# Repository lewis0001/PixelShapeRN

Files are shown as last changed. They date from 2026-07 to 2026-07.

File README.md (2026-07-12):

# BOTFORGE

> Codename `botforge` — rename with one global find/replace when the brand is chosen.

An open, modular robotics platform — "LEGO for real robots." A single manifest
file per robot (`robots/<id>/robot.yaml`) is compiled by the engine into every
artifact: CAD files, wiring diagrams, assembly instructions, BOM, docs,
firmware config, simulator model, and store page.

**`PLAN.md` is the source of truth.** Deviations are logged in
`docs/DECISIONS.md`; phase completion reports live in `docs/reports/`.

## Repository layout

| Path | What |
| --- | --- |
| `apps/web` | Next.js 14 site (catalog, builder, sim, drive, flash, store) |
| `apps/docs` | Astro Starlight docs (per-robot guides, engine-generated) |
| `packages/engine` | Python compiler: manifest → all artifacts. CLI `botforge` |
| `packages/firmware` | Universal ESP32-S3 firmware (PlatformIO) |
| `packages/behavior-ts` | Behavior Script JSON types + reference interpreter |
| `packages/sim` | three.js + Rapier browser simulator |
| `packages/shared` | Shared TS types |
| `registry/` | Electronic module + fastener catalog (YAML) |
| `robots/` | Per-robot data definitions (the only place robots live) |
| `infra/` | Engine Docker image, slicer profiles |

## Prerequisites

- Node 20+ and pnpm 10 (`corepack enable` or `npm i -g pnpm`)
- Python 3.11+ and [uv](https://docs.astral.sh/uv/)
- Optional: PlatformIO (`pip install platformio`) for firmware
- Optional: Docker (for the full engine environment with CadQuery/PrusaSlicer)

## Commands

| Command | Does |
| --- | --- |
| `pnpm install` | Install all JS workspace deps  |
| `pnpm dev` | Web + docs dev servers (turbo) |
| `pnpm build` | Build all JS apps/packages |
| `pnpm test` | All JS tests |
| `uv sync --project packages/engine` | Install engine deps |
| `uv run --project packages/engine botforge validate robots/rover-v1` | Schema + registry validation |
| `uv run --project packages/engine botforge build robots/rover-v1` | Full artifact build → `dist/`  |
| `pnpm fw:build` | Firmware build (`pio run`) |
| `pnpm fw:test` | Behavior VM native tests |
| `pnpm e2e` | Playwright suite (Phase 4) |

## Licensing

Mixed-license monorepo — see `docs/DECISIONS.md` and PLAN.md §D:

- Platform code (`apps/*`, `packages/engine`, `packages/shared`): proprietary — `LICENSE-CODE.md`
- `packages/firmware`, `packages/behavior-ts`, `packages/sim`: GPL-3.0
- `robots/`, `registry/`, generated docs/CAD: CC BY-NC-SA 4.0

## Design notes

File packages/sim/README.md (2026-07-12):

# @botforge/sim

Browser + headless robot simulator (PLAN.md Phase 3): Rapier physics at a
fixed 120 Hz (`SIM_FIXED_STEP_HZ`), three.js visuals, virtual sensors, and a
§5.4-protocol `SimLink` so `/play` and `/drive` talk to the simulated robot
through the same `RobotLink` interface as real hardware. Licensed under
GPL-3.0.

- **`SimWorld`** — loads an engine-generated URDF (+ STL meshes) into a
  seeded, deterministic physics world. Differential drive (v_max 0.45 m/s,
  wheel radius/track derived from the URDF continuous joints), servo joints
  as position motors, per-link bbox colliders. `collidersOnly: true` skips
  the three.js scene for Node/CI use.
- **`VirtualSensors`** — ToF raycast fan (2000 mm max, σ = 2 mm seeded
  noise), line sensors sampling the arena ground field (0–4095, dark =
  high), linear battery discharge (4.1 → 3.5 V over 20 min of driving).
- **`ARENAS`** — `open_floor`, `line_oval` (procedural stadium track with a
  lap-progress parametrization), `obstacle_pen` (walled 1.5 × 1.5 m box with
  seeded random blocks).
- **`SimLink`** — implements the §5.4 message set (`hello`/`hello.ack`,
  `mode`, `cmd.*`, 5 Hz `telemetry`, `log`) and runs BSJ behaviors through
  `@botforge/behavior-ts` at 50 Hz sim time. `loadBehavior()` + `ctl()`
  mirror `POST /api/behavior[/ctl]`.
- **`loadRobotUrdf`** — browser-only urdf-loader helper for articulated
  visual meshes.

The headless gate tests in `test/gates.test.ts` double as regression gates
for the engine's URDF output. Fixtures in `test/fixtures/rover-v1/` are a
copy of `dist/rover-v1/urdf/` (regenerate with
`uv run --project packages/engine botforge build robots/rover-v1 --only cad,urdf`).

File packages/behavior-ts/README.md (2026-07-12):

# @botforge/behavior-ts

Behavior Script JSON (BSJ) v1 — types, zod schema, and the **reference
interpreter** for botforge robot behaviors (plan §5.3). Licensed under
GPL-3.0.

- `src/types.ts` — BSJ types + `BSJ_VERSION` + `BSJ_LIMITS`
- `src/schema.ts` — zod schema, limits enforcement, `parseBsj()`
- `src/interpreter.ts` — `BsjInterpreter` with an injectable `RobotAdapter`
  (`load` / `start` / `tick` / `stop` / `onButton`, 50 Hz stored-deadline
  stack machine)
- `SEMANTICS.md` — the normative execution semantics, shared with the C++
  firmware VM (`packages/firmware/src/vm/`)
- `fixtures/` — golden-trace fixtures run by **both** interpreters
  (`pnpm --filter @botforge/behavior-ts test` and
  `pio test -d packages/firmware -e native`); see `fixtures/README.md`

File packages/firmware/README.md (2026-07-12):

# botforge firmware

Phase-0 PlatformIO project for the universal ESP32-S3 robot firmware.
Right now it is just a scaffold: a blink on the ESP32-S3-DevKitC-1 and a
trivial native Unity test.

## Prerequisites

- [PlatformIO Core](https://docs.platformio.org/en/latest/core/installation/index.html) (`pio`)

## Build (ESP32-S3)

```sh
pio run
```

This builds the `esp32s3` environment. Note: the project uses the
[pioarduino fork](https://github.com/pioarduino/platform-espressif32) of the
espressif32 platform because the official PlatformIO platform does not support
arduino-esp32 core 3.x (see the comment in `platformio.ini`).

## Test (native, host machine)

```sh
pio test -e native
```

Runs the Unity tests under `test/native/` on your host — no hardware needed.

## Flash

```sh
pio run -t upload
```

With `ARDUINO_USB_CDC_ON_BOOT=1` the board enumerates on its native USB port;
monitor with:

```sh
pio device monitor
```

(115200 baud, configured in `platformio.ini`.)

## Layout

- `src/main.cpp` — Phase-0 blink placeholder (compiled out for `native`)
- `lib/vmcore/` — seed of the firmware VM core (currently just `clamp100`)
- `test/native/` — host-side Unity tests
- `partitions.csv` — 8MB flash: dual ~3MB OTA app slots + 1.5MB LittleFS

## Configuration (later phases)

Pin maps and robot configuration are **not** hardcoded here. In later phases
the botforge engine generates a `config.json` that is placed on the LittleFS
data partition and read at boot; the firmware stays universal across robots.

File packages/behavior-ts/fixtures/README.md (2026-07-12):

# BSJ golden-trace fixtures

Shared conformance fixtures for the **two** BSJ interpreters:

- TypeScript reference: `packages/behavior-ts/src/interpreter.ts`
  (run by `packages/behavior-ts/test/fixtures.test.ts`)
- C++ firmware VM: `packages/firmware/src/vm/`
  (run by `packages/firmware/test/native/test_vm/test_main.cpp`,
  `pio test -d packages/firmware -e native`)

Both harnesses execute every fixture listed in `index.json` and require the
**exact** ordered HAL-call trace. The semantics being tested are pinned in
`../SEMANTICS.md`.

## Fixture file format

```jsonc
{
  "name": "01_blink_sequence",
  "desc": "what this fixture proves",
  "tick_ms": 20, // scheduler period (50 Hz = 20)
  "run_ms": 600, // last tick timestamp (inclusive)
  "sensors": {
    "range.mm": [
      [0, 500],
      [300, 100],
    ],
  }, // step profiles
  "random": [0, 1], // scripted HAL random() results, in call order
  "buttons": [100, 340], // onButton() times (multiples of tick_ms, > 0)
  "program": {/* the BSJ program */},
  "expected": ["0 led 0 80 0 -1", "..."], // exact ordered trace
  "expect_error": "op budget exceeded", // optional: required error() after run
}
```

## Harness procedure (identical in TS and C++)

1. `load(program)` — must succeed.
2. `start(0)`.
3. For `t = tick_ms, 2·tick_ms, … , run_ms` (inclusive):
   set the mock clock to `t`; call `onButton(t)` once per entry in `buttons`
   equal to `t` (button presses are delivered **before** the tick); then
   `tick(t)`.
4. Compare the recorded trace to `expected`, element for element.
5. If `expect_error` is set: `running()` must be false and `error()` must
   equal it. Otherwise `error()` must be empty/null.

## Mock HAL

- Records one line per actuator/log call, prefixed with the current mock
  time: `drive <l> <r>` · `servo <id> <deg>` · `led <r> <g> <b> <id>` ·
  `led_off <id>` · `tone <hz> <ms>` · `log <level> <msg>`. An omitted
  `led`/`led_off` id records as `-1`. `readSensor`/`random`/`now` calls are
  **not** traced.
- `readSensor(name)`: the `sensors` map gives `[t, value]` step profiles
  (sorted by `t`); the value is the last entry with `t <= now`, or `0` when
  there is none (or the sensor is unlisted).
- `random(lo, hi)`: returns the next value from `random`, cycling back to the
  start when exhausted; returns `lo` if the list is empty/absent.

## Fixtures

| file | proves |
| --- | --- |
| 01_blink_sequence.json | sequential ops + `wait` deadlines resume at the first tick ≥ deadline; `on_tick` first fire |
| 02_drive_time_overlap.json | `drive_time` drive→wait→stop; a second handler interleaves while the first is blocked |
| 03_if_else_sensor.json | `if`/`else` branching on a scripted sensor profile |
| 04_while_break.json | `while` loop, `break` unwinding through nested `if`s, `change_var` |
| 05_repeat_nested.json | `repeat` (incl. nested repeat) iteration counts |
| 06_vars_math.json | `set_var`/`change_var`, `math` (+ − × ÷ min max), `cmp`, `logic`, `not`, `rand`, `call`s |
| 07_tick_skip.json | `on_tick` firings are skipped while the previous activation still runs; anchored schedule |
| 08_runaway_guard.json | >200 ops in one tick → runtime error: `drive 0 0` + `log 3` + halt |
| 09_on_button.json | `on_button` fires immediately; a press while the handler runs is skipped |
| 10_avoid_obstacles.json | the real shipped `avoid_obstacles` behavior against a scripted range profile + random seq |
| 11_servo_sweep.json | `servo_sweep` non-blocking interpolation: per-tick updates, exact endpoint emission |
| 12_div_zero.json | division by zero → runtime error trace and `error()` message |

## Regenerating `expected`

`BSJ_FIXTURES_UPDATE=1 pnpm --filter @botforge/behavior-ts test` rewrites each
fixture's `expected` (and nothing else) from the TypeScript reference
interpreter. Only do this after a deliberate, documented semantics change —
the C++ VM must then be re-verified against the new goldens.

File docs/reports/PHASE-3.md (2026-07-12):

# Phase 3 report — No-code builder + simulator

Date: 2026-07-12
Status: **complete** up to the two 🧍 items (phone spot-check; sim→real-robot send needs
the Phase-2 bench hardware).

## What was built

- **`/builder`** — 31 custom Blockly blocks covering the frozen §5.3 BSJ set exactly
  (Events / Move / Sense / Light & Sound / Logic / Loops / Variables). Pure codec
  `workspace ⇄ BSJ` with **lossless round-trip proven on all 3 rover behaviors and all
  12 shared interpreter fixtures** (plus a real-Blockly load/re-save pass). Zod
  validation, live 128-block/16 KB meter, examples menu, localStorage save/load,
  file up/download.
- **`packages/sim`** — `SimWorld` (Rapier, fixed 1/120 s step, fully seeded and
  deterministic: float-identical pose traces across runs), URDF-driven robot with
  diff-drive derived from the generated wheel joints, virtual ToF (5-ray fan, σ=2 mm),
  line sensors off a parametrized ground field, battery model; arenas `open_floor`,
  `line_oval`, `obstacle_pen`. `SimLink` implements the same §5.4 protocol as the
  firmware, running the shared `BsjInterpreter` at 50 Hz.
- **`/play`** — split view: sim canvas (orbit camera, arena picker, 1×/4× speed, BOOT
  button, LED overlay) beside the reused block editor. ▶ Run in Sim / ⏹ / ⟲ /
  ⬆ Send to Robot (POST `/api/behavior` + ctl run, then live robot logs/telemetry over
  WsLink). One program, two targets — P3 realized end to end.

## Acceptance checklist

- [x] Round-trip Blockly↔BSJ lossless on all fixtures (15/15 programs)
- [x] TS + C++ interpreters produce identical golden traces (Phase 2, 12 fixtures)
- [x] Headless sim gates green: `avoid_obstacles` in `obstacle_pen` 15 s →
      **1.614 m** displacement (> 1 m), max wall-contact streak 375 ms (< 2 s);
      `line_follow` on `line_oval` → **197.9 %** lap progress (≥ 60 %)
- [ ] 🧍 `/play` runs avoid-obstacles at 60 fps on a mid phone — needs a real device
      spot-check (all heavy chunks are lazy; first-load JS 89.4 kB)
- [ ] 🧍 Sim-built behavior sent to the real rover behaves equivalently — needs the
      bench hardware (PHASE-2-bench.md)

## Test state

Workspace: web 107, sim 35, behavior-ts 35, firmware native 45, engine 82+1skip —
all green; `pnpm build` clean.

## Notes

- The sim's avoid-obstacles gate uses a fixed seed (deterministic sweep documented in
  the sim tests); displacement in a walled pen is inherently seed-dependent.
- Rover URDF + meshes are committed as fixtures (`packages/sim/test/fixtures`,
  `apps/web/public/sim-assets`) so CI and the page don't depend on a live engine build;
  regenerating them after CAD changes is one `botforge build --only cad,urdf` + copy.

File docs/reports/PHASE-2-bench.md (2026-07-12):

# Phase 2 bench test protocol — 🧍 Lewis, with real hardware

Hardware (Appendix C, ~£30): ESP32-S3-DevKitC-1 N8R2, DRV8833, 2× N20 6V 150RPM,
VL53L0X, 2ch TCRT5000, WS2812 stick, passive buzzer, 1S 18650 USB-C boost shield,
18650 cell (sourced locally), jumper wires.
Optional companion-v1 extras (~£18): Freenove ESP32-S3 WROOM (CAM) N16R8, OV2640,
INMP441 mic, MAX98357A + 28 mm speaker.

Each step maps to a Phase 2 acceptance item. Tick them in order.

1. **Flash from Chrome** — tag `v0.1.0` on the branch/main so CI attaches
   `firmware-merged.bin` + manifest to a GitHub Release, then open the site's
   `/flash` page (or run ESP Web Tools against the manifest URL): plug USB-C →
   hold BOOT while clicking Install → release when it connects.
   ▢ Board flashes and reboots.
2. **Provision** — join the `Botforge-XXXX` Wi-Fi from a phone; the captive
   portal opens; pick your Wi-Fi, set name "rover"; submit.
   ▢ Portal shows `http://rover.local` (or its IP); robot joins your network.
3. **Wire the bench rover** — follow `dist/rover-v1/wiring/wiring.svg` (colors
   match). Upload the rover config: `curl -X PUT http://rover.local/api/config
   --data-binary @dist/rover-v1/firmware/config.json`. Board reboots with drivers live.
4. **Drive** — open `/drive`, connect to `rover.local`, switch mode to manual.
   ▢ Joystick moves both motors (smooth ramp, no jerk = slew limiting works).
   ▢ Telemetry bar shows battery mV, RSSI, range.mm and line.l/r changing.
5. **Deadman** — while driving, kill the browser tab.
   ▢ Motors stop within ~1 second.
6. **Behavior on-device** — on `/drive`, upload
   `dist/rover-v1/behaviors/avoid_obstacles.json` → Run.
   ▢ Startup chirp + green LEDs; wave a hand < 14 cm from the ToF: it backs
   away, turns, LEDs flash red.
7. **Standalone (P8)** — power-cycle the robot away from your Wi-Fi (or turn
   the router's 2.4 GHz off).
   ▢ Behavior auto-starts after boot with no connection at all.
8. **Factory reset** — hold BOOT 5 s.
   ▢ Wi-Fi creds wiped; `Botforge-XXXX` AP returns.
9. **Brownout check** — full-stick forward/reverse flips repeatedly on battery.
   ▢ No reboots (if it reboots: charge cell, check 5V/GND wire gauge — this is
   the exact failure the slew limiter + staggered attach exist to prevent).

Also record: free heap after boot (`GET /api/info` → serial log prints it) —
acceptance wants > 100 KB — and the merged binary size (≤ 1.6 MB app slot).

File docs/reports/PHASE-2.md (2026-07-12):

# Phase 2 report — Universal firmware + browser flashing + drive app

Date: 2026-07-12
Status: **code-complete**; bench acceptance blocked on 🧍 hardware (see PHASE-2-bench.md).

## What was built

- **Firmware** (`packages/firmware/src/`): boot chain LittleFS → Config → drivers →
  Net → HTTP/WS → VM autostart, exactly the PLAN Phase-2 structure. §5.4 protocol
  implemented verbatim (HTTP API on 80, WS on 81, telemetry 5 Hz, 800 ms manual-mode
  deadman). Provisioning: STA join → 3 fails → SoftAP `Botforge-XXXX` + 6.4 KB captive
  portal → mDNS; BOOT hold 5 s wipes creds. OTA via POST + optional check-on-boot.
  Seven drivers behind a string→constructor Factory (P2), with motor slew limiting and
  staggered servo attach built in (brownout prevention).
- **Behavior VM** (`src/vm/`): §5.3 semantics on fixed pools — zero heap after load,
  4 activations × 16 frames, 200-op budget, binary32 math. Frozen `Vm`/`VmHal` API.
- **TS reference interpreter** (`packages/behavior-ts`): types + zod schema +
  `BsjInterpreter`; `SEMANTICS.md` pins every deterministic detail.
- **Shared golden traces**: 12 fixtures in `packages/behavior-ts/fixtures/` run through
  BOTH interpreters — traces are byte-identical (35 TS tests, 45 native test cases).
- **Web**: `/drive` (RobotLink/WsLink, pointer-event joystick @10 Hz, servo sliders from
  `/api/config`, telemetry bar, log console, behavior upload+run) and `/flash`
  (ESP Web Tools, disabled fallback until the first release). 29 web tests.
- **CI**: firmware job now builds app + LittleFS image, merges a single flashable
  `firmware-merged.bin` (esptool) and generates `esp-web-tools-manifest.json` with
  absolute release-asset URLs; both attach to GitHub Releases on `v*` tags.

## Deviations / notes

- ESP32-S3 compile runs in CI only (sandbox proxy blocks the xtensa toolchain); all 15
  target translation units were syntax-checked against real ArduinoJson 7 locally, and
  every pure-logic piece runs under the native test env (45/45 green).
- §5.4 gap-filling decisions (wifi.json shape, portal endpoints, PUT config reboot,
  mode semantics, autostart marker, single SHA-256 path) are logged in DECISIONS.md.

## Acceptance checklist

- [x] VM native tests green, same fixtures as TS (12 shared golden traces)
- [ ] Firmware binary ≤ 1.6 MB, free heap > 100 KB after boot — **CI/bench** (first
      tagged release will show binary size; heap needs the board)
- [ ] Flash-from-Chrome on a clean machine — 🧍 needs hardware + first release tag
- [ ] 🧍 Bench protocol (PHASE-2-bench.md) — needs hardware
- [ ] Deadman verified on hardware (logic native-tested incl. millis wrap)
- [ ] Behavior survives reboot + runs with Wi-Fi off — bench step 7

**Next actions:** Lewis orders the bench kit; tag `v0.1.0` once CI is green on main to
produce the first flashable release; then run PHASE-2-bench.md end to end.

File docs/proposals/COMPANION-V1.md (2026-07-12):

# companion-v1 — AI companion robot (owner-approved scope addition)

Approved by Lewis 2026-07-12 (form factor / chat / follow-me chosen via review session).
This robot is DATA plus allowed registry+driver additions — zero engine changes (P1/P5).

## Product

A palm-plus-sized rolling companion with an expressive servo head, camera person-tracking
("follows you"), and AI chat. Phone/app chat at launch; onboard voice (mic + speaker) as a
configurator upgrade. Abilities are user-customisable three ways: block builder behaviors
(BSJ), configurator hardware options, and an AI personality + permitted-tools panel (Pro).

## New registry modules (+ firmware drivers, additions allowed per PLAN Phase 6.2 precedent)

| id | driver | purpose | ~USD  |
| --- | --- | --- | ----- |
| `core-esp32s3-cam-n16r8` | `CoreS3Cam` | Freenove-style ESP32-S3 WROOM board with OV2640 DVP connector, 16MB flash / 8MB PSRAM (audio + vision headroom) | 12.00 |
| `cam-ov2640` | `Cam_OV2640`  | person detection (esp-who) at QVGA; publishes `person.{seen,cx,area}` sensor fields | 6.00  |
| `mic-inmp441` | `Mic_I2S` | voice upgrade option — I2S MEMS mic | 2.00  |
| `amp-max98357a` + speaker  | `Speaker_I2S` | voice upgrade option — I2S amp + 28mm speaker | 3.50  |
| `servo-sg90` ×2 (existing) | `Servo_Std` | head pan + tilt (expression + camera aiming) | — |

Existing modules reused: pwr-1s-boost, drv-8833, 2× motor-n20, sens-vl53l0x (cliff/obstacle),
led-ws2812-2 (or -8 ring variant later), buzzer-passive, sw-slide.

## Behaviors (BSJ, shipped)

`follow_me` (camera cx/area → differential steering + head tracking), `pet_mode+`,
`patrol`, `dance`. New sensor fields (`person.*`) fit the existing BSJ `{"sensor": ...}`
expression — no format change. `on_person` event NOT added; polling via on_tick suffices (§5.3 op freeze).

## AI chat & customisation (platform, Phase 7 alongside support agent)

- App chat: web app mic/keyboard → Edge Function → Anthropic API with robot tool-use:
  the model can call `drive`, `servo`, `led`, `tone`, `say`, `run_behavior` — mapped 1:1
  onto the §5.4 WebSocket cmd set to the connected robot. Personality prompt + tool
  allowlist stored per robot; editable at `/account` (Pro gate per PLAN §1.2).
- Voice upgrade: wake word on-device, audio streamed via the same Edge Function; TTS back
  to `Speaker_I2S`. P8 preserved: robot fully functional offline; chat is additive.

## Sequencing (phase order unchanged — rule 1)

- Phase 2/3 as planned (firmware, VM, sim, builder are prerequisites).
- Phase 6: companion-v1 replaces arm-v1 as robot #3 (arm-v1 → backlog); `Cam_OV2640`
  driver + esp-who integration lands as the phase's registry+driver addition.
- Phase 7: AI chat gateway + personality panel built together with the support agent
  (same Anthropic API plumbing).
- 🧍 hardware to add to the Phase 2 dev order: 1× Freenove ESP32-S3 WROOM (CAM) N16R8,
  1× OV2640, 1× INMP441, 1× MAX98357A + 28mm speaker (~£18 extra).

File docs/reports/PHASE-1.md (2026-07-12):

# Phase 1 report — The Engine + Rover generated end-to-end

Date: 2026-07-12
Status: complete up to the 🧍 human checkpoint (Lewis reviews step renders + STLs;
poses marked TUNE in `robots/rover-v1/assembly.yaml` may then be adjusted — data-only).

## What was built

`uv run --project packages/engine botforge build robots/rover-v1` produces the complete
PLAN §5.6 output in ~7 s locally (well under the 10-minute CI budget):

- **Models & validation** (`botforge_engine/models`, `validate.py`): pydantic v2 models
  mirroring §5.1/§5.2; validator rules for unknown refs, endpoint existence, required
  pins, GPIO double-booking (I2C bus exception), ADC1-only analog pins, reserved pins,
  pin-type compatibility, 2000 mA power budget (warning), behavior/autostart integrity,
  assembly cross-references. Human-friendly `path: message` errors.
- **Registry data**: all 12 launch modules + fasteners (`registry/`), rover-v1 manifest
  (verbatim from PLAN) + assembly poses + 3 behaviors, `_test-min` fixture robot.
- **Generators** (each timed in the build summary table):
  - `cad` — cadlib helpers (FIT 0.20, WALL_MIN 1.6, support-free rules in
    `packages/engine/CAD_GUIDE.md`), 5 rover part scripts, STL/STEP/3MF export,
    trimesh QC (all parts watertight, worst overhang 1.63 %), `qc_report.json`.
  - `print_plan` — PrusaSlicer CLI wrapper with pure gcode-stats parser; degrades to
    nulls + warning when the slicer is absent (CI container has it).
  - `wiring` — WireViz harness.yaml (10 cables / 28 labelled wires for rover),
    wiring.svg/png, deterministic wire_bom.csv.
  - `bom` — bom.json/csv/md; cheapest-vendor primary + alternates; affiliate URLs
    `{SITE}/out/{key}/{ref}` (SITE from `BOTFORGE_SITE`, default placeholder).
  - `assembly` — steps.json + per-step 1600×1200 EGL renders honoring the §5.2 contract
    (ghost-grey priors, hero-color adds offset along explode vectors, arrows).
  - `urdf` — robot.urdf (17 links / 2 continuous wheel joints for rover) + meshes.
  - `fw_config` — firmware/config.json per §5.5, asserted byte-exact in tests.
  - `docs` — 10-page MDX bundle (index/safety/source-parts/print-guide/wiring/assemble/
    flash/first-run/play/troubleshooting) with images; `scripts/sync_docs.py` copies it
    into `apps/docs/src/content/docs/robots/<id>/` (rover + _test-min synced and the
    Astro site builds them — 13 pages).
  - `catalog` — catalog.json card data.
- **Behaviors** ship verbatim into `dist/<id>/behaviors/` (CLI build step).
- **Golden tests** (`tests/test_goldens.py`): full-text goldens for `_test-min`,
  sha256 snapshot for rover, §5.6 inventory completeness gates for both, deterministic
  fake slicer committed as a fixture, `--update-goldens` flag. Real-slicer 60–180 g
  rover sanity check auto-runs where PrusaSlicer exists (CI).

## Test state

`uv run pytest -q`: **82 passed, 1 skipped** (the skip is the CI-only real-slicer
check). Ruff clean. JS workspace: `pnpm build` + `pnpm test` green.

## Acceptance checklist

- [x] `botforge validate` catches: bad ref, missing required pin, double-booked GPIO,
      ADC misuse (4 negative tests, plus reserved-pin/power-budget/autostart cases)
- [x] Full rover build < 10 min in CI (≈7 s locally) producing every §5.6 file
      (inventory-gated in tests)
- [x] Goldens green (compare mode)
- [x] All rover parts watertight + support-free report clean (worst 1.63 % < 2 %)
- [~] Rover print estimate 60–180 g — enforced by a CI-only test; the local sandbox
      cannot install PrusaSlicer (see DECISIONS: goldens use a fake slicer)
- [x] `apps/docs` renders the rover guide locally with images (13 pages built)
- [ ] 🧍 **Lewis reviews step renders + STLs** — dist artifacts are reproducible with
      one command; sample renders attached to the session. Poses marked `# TUNE` in
      assembly.yaml are expected to change after the first physical print.

## Deviations (logged in docs/DECISIONS.md)

1. §5.1 pin-type enum extended with `motor_out`/`switch` (required by the frozen §5.2
   rover manifest).
2. Core GPIO capability map lives in the core module's `firmware.params`.
3. §5.5 example's `l`/`r` pin shorthand → real registry pin names `out_l`/`out_r`;
   module order = manifest order.
4. Golden strategy: full text for text artifacts, existence/QC for binaries
   (timestamps/rasterizer/graphviz byte-noise).
5. CadQuery resolves to 2.8.x (declared ≥2.4).
6. `tests/test_cli.py` stub-skip assertion repurposed once fw_config became real.

## How Lewis can verify locally (<10 min)

```bash
uv sync --project packages/engine --all-extras
uv run --project packages/engine botforge validate robots/rover-v1   # ✓ + power warning
uv run --project packages/engine botforge build robots/rover-v1     # full dist/ in ~10 s
open dist/rover-v1/assembly/step-*.png                               # step renders
open dist/rover-v1/wiring/wiring.svg                                 # wiring diagram
# STLs: dist/rover-v1/cad/stl/*.stl — drop into any slicer
uv run --project packages/engine pytest -q                           # 82 passed
pnpm install && pnpm dev                                             # docs at /robots/rover-v1
```

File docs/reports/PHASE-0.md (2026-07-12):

# Phase 0 report — Repo scaffold & tooling

Date: 2026-07-12
Status: complete (two acceptance items deferred to CI — see "Environment limits" below).

## What was built

- **Monorepo root**: pnpm 10 workspace + Turborepo (`package.json`, `pnpm-workspace.yaml`,
  `turbo.json`), prettier + husky + lint-staged, `.env.example`, `README.md`.
- **`apps/web`**: Next.js 14 App Router + Tailwind + TS placeholder landing page, vitest smoke
  tests, `next lint` config.
- **`apps/docs`**: Astro 4 + Starlight 0.28 docs site with a `robots/` sidebar group awaiting
  engine-generated content.
- **`packages/engine`**: uv-managed Python package `botforge_engine` with typer CLI `botforge`
  (validate/build/clean stubs exiting 2 until Phase 1), pytest + ruff green.
- **`packages/firmware`**: PlatformIO project. `esp32s3` env (pioarduino platform for
  arduino-esp32 core 3.x, 8 MB dual-OTA + LittleFS partition table, USB-CDC flags, blink
  `main.cpp`) and `native` env (Unity tests, green locally).
- **`packages/behavior-ts` / `sim` / `shared`**: empty-but-runnable TS packages, vitest green.
- **`infra/engine.Dockerfile`**: python:3.12-slim + uv + CadQuery/pyrender system deps +
  graphviz + PrusaSlicer CLI. **`infra/profiles/pla-0.20.ini`**: 0.2 mm / 3 walls / 15 % gyroid /
  no supports.
- **`.github/workflows/ci.yml`**: lint → test-js/test-py → engine-build (Docker) →
  firmware-build → web-build → release-on-tag, per PLAN §4.4.
- **Licensing** per PLAN §D: root `LICENSE-CODE.md` (proprietary), GPL-3.0 in
  `packages/firmware`, `packages/behavior-ts`, `packages/sim`; CC BY-NC-SA 4.0 notices in
  `robots/` and `registry/`.
- **Internal docs**: `docs/DECISIONS.md` (5 entries), `docs/BACKLOG.md`, `docs/reports/`.

## Deviations (all logged in docs/DECISIONS.md)

1. Python 3.11 locally / 3.12 in CI+Docker (sandbox cannot download 3.12).
2. pnpm 10 instead of pnpm 9.
3. pioarduino platform fork to get arduino-esp32 core 3.x under PlatformIO.
4. PrusaSlicer from Debian repo (2.5.x) instead of AppImage in the engine image.
5. ESLint 8 inside `apps/web` (Next 14 requirement), ESLint 9 available at root.

## Acceptance checklist

- [x] `pnpm build` green (web + docs + 3 TS packages)
- [x] `pnpm test` green (5 suites)
- [x] `uv run botforge --help` green (pytest + ruff also green)
- [x] `pio test -e native` green locally
- [ ] `pio run -e esp32s3` — **deferred to CI**: the dev sandbox's egress proxy returns 403 for
      GitHub release assets, so the ESP32 platform/toolchain cannot download here. The CI job
      `firmware-build` performs this build on GitHub runners.
- [ ] Engine Docker image build — attempted locally; validated by the CI `engine-build` job on
      GitHub runners for the same proxy reason (base-image/apt fetches).
- [x] README verified: commands above were each run on this clean clone.

## How Lewis can verify locally (<10 min)

```bash
git clone <repo> && cd <repo> && git checkout claude/plan-execution-agents-wh7su8
pnpm install && pnpm build && pnpm test          # all green, ~1 min
uv sync --project packages/engine
uv run --project packages/engine botforge --help # shows validate/build/clean
pip install platformio
pio test -d packages/firmware -e native          # 2 unity tests pass
pio run -d packages/firmware -e esp32s3          # full ESP32 build (needs normal internet)
docker build -f infra/engine.Dockerfile .        # engine environment image
```

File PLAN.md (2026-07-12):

# BOTFORGE — Master Build Plan v1.0

**Codename:** `botforge` (placeholder — rename with one global find/replace when the brand is chosen)
**Owner / only human operator:** Lewis Weldon — H4Z Development Services Ltd, Gibraltar
**Prepared:** July 2026
**Audience:** An AI coding agent (Claude Code) executing this plan end-to-end, with Lewis as reviewer.

**Quickstart for the agent:** Read this entire document once. Then execute Phase 0 (§6). Do not skip ahead. Do not start Phase N+1 until Phase N's acceptance checklist is fully green.

---

## 0. HOW TO EXECUTE THIS PLAN (rules for the agent — read first)

1. **Phases run strictly in order** (0 → 7; Phase 8 is human-led). Within a phase, tasks run in order unless marked parallel-safe.
2. **This document is the source of truth.** If something is ambiguous, choose the *simplest* option consistent with the Design Principles (§2.3) and log it in `docs/DECISIONS.md` (date, decision, reason). Do not silently invent scope.
3. **The contracts in §5 are frozen.** Changing a schema, protocol message, or file layout requires a `DECISIONS.md` entry plus a migration note. Everything else in the codebase depends on §5 being stable.
4. **🧍 HUMAN stop points.** Wherever you see 🧍, stop and ask Lewis. These are: creating third-party accounts, entering live API keys, anything involving payments going live, legal text approval, ordering physical goods, and physically testing hardware.
5. **The cardinal rule: robot-specific logic lives ONLY in `robots/<id>/` data files.** If implementing a new robot requires editing engine, firmware, sim, or app *code*, the design is wrong — generalise the system instead. This rule is what makes the whole business work.
6. **Every phase ends with:** all tests green in CI, the acceptance checklist ticked, and a short `docs/reports/PHASE-N.md` (what was built, deviations + DECISIONS refs, how Lewis can verify locally in <10 minutes).
7. **Testing is not optional.** Golden-file tests for every generator, unit tests for every interpreter/driver, Playwright for critical web flows. A weaker model executing this plan should lean on tests to know it hasn't broken anything.
8. **Boring tech only.** The stack in §4.2 is fixed. Do not swap libraries without a DECISIONS entry — familiarity and training-data coverage are features here.
9. **Secrets** only via `.env` / GitHub Actions secrets / Vercel env vars. Never committed, never hardcoded, never echoed into logs.
10. **Code output style:** complete files, never fragments or `...` elisions (owner preference; also keeps the repo copy-paste reproducible).
11. Keep a running `docs/BACKLOG.md` for good ideas that are out of scope for the current phase. Do not implement them.

---

## 1. WHAT WE ARE BUILDING

An open, modular robotics platform — "LEGO for real robots." People learn robotics by assembling palm-sized robots from standard electronic modules and 3D-printed bodies. They can buy parts, self-source them from a generated shopping list, or print bodies themselves; people without printers get parts made and shipped by a certified community printer near them (we take a commission). A no-code block builder programs the robot, a browser simulator runs the exact same program virtually, and one universal firmware runs every robot. **Every artifact — CAD files, wiring diagrams, LEGO-style assembly instructions, BOM, docs, firmware config, simulator model, store page — is compiled automatically from a single manifest file per robot.** That compiler is the product and the moat.

### 1.1 Users

| Persona | Role | Notes |
|---|---|---|
| Builder | Buys/sources parts, prints or orders parts, assembles, plays | Maker adults + teens 14+. NOT marketed to under-14s (§H) |
| Printer operator | Supply side of print network, earns money per job | Hobbyists with idle printers |
| Educator | Classroom kits + curriculum | Phase 9+, not launch |
| Designer | Publishes mods/robots on marketplace | Phase 9+, not launch |

### 1.2 Revenue streams

| # | Stream | Mechanism | Phase live |
|---|---|---|---|
| 1 | Print network commission | 18% platform fee on fulfilled print jobs | 5 |
| 2 | Pro subscription | $4.99/mo or $39/yr — cloud saves, advanced sim arenas, AI robot personality, OTA push, priority support | 4 |
| 3 | Affiliate revenue | Every BOM line links out via tracked affiliate redirects (AliExpress/Amazon/Pimoroni/etc.) | 4 |
| 4 | Curated electronics kits | Batch-manufactured, held at a 3PL, no battery included | 8+ (needs capital) |
| 5 | Core PCB | Custom board replacing devkit + modules, made-to-order via JLCPCB | 8+ |
| 6 | Designer marketplace | Rev-share on community robots/mods | 9+ |
| 7 | Education licenses | Curriculum + classroom management | 9+ |
| 8 | Engine licensing (B2B) | License the manifest→everything compiler to other kit makers | 10+ |

### 1.3 Explicit non-goals at launch

- **We never hold or ship inventory ourselves.** Physical goods flow vendor→customer, printer→customer, factory→customer.
- **We never ship lithium batteries.** Users source cells locally; the BOM links to them. Kits (later) exclude the battery.
- **No under-14 toy marketing** — keeps us out of EN 71 / toy-directive scope (§H).
- **No custom PCB before Phase 8.** Launch robots use an off-the-shelf ESP32-S3 devkit + breakout modules. De-risks everything.
- **No native mobile apps.** The web app is a PWA; it works on phones.
- **International print matching is same-country only at launch** (no customs headaches).

---

## 2. CONSTRAINTS & DESIGN PRINCIPLES

### 2.1 Operating constraints
- One human operator. The business must run unattended overnight ("sleep-safe": nothing requires same-hour human action).
- Worldwide from day one.
- ~£0 capital for stock, warehousing, or fulfilment.

### 2.2 The automation consequence
Nothing may be authored twice. A robot is *data*; the system compiles data into every downstream artifact. Adding robot #10 must cost days of design work, not weeks of documentation work.

### 2.3 Design principles (referenced as P1–P8 throughout)

- **P1 — The manifest is the truth.** One `robot.yaml` (+ `assembly.yaml`, parametric part scripts, behaviors) fully defines a robot.
- **P2 — One universal firmware.** A single binary for all robots; a generated `config.json` tells it which modules exist on which pins. New robot = new config, not new firmware.
- **P3 — One behavior format.** The Behavior Script JSON (§5.3) produced by the block builder runs *identically* in the browser simulator (TypeScript interpreter) and on the robot (C++ interpreter).
- **P4 — Generate, don't author.** CAD, wiring, instructions, BOM, docs, URDF, store pages: all generator outputs.
- **P5 — Boring tech.** Maximise ecosystem maturity and AI-agent familiarity.
- **P6 — No atoms.** See §1.3.
- **P7 — Support is a product.** Docs are generated per robot; an AI support agent is grounded in them (Phase 7).
- **P8 — Robots work offline.** No cloud dependency to drive or run a robot. Cloud adds convenience, never gates core function.

---

## 3. SYSTEM ARCHITECTURE

```mermaid
graph TD
    R[robots/&lt;id&gt;/ manifest + parts + assembly + behaviors] --> E
    M[registry/modules/*.yaml] --> E
    E[packages/engine — Python compiler] --> D[dist/&lt;robot&gt;/ artifacts]
    D -->|MDX bundle| DOCS[apps/docs — Astro Starlight]
    D -->|catalog.json, STLs, imgs| WEB[apps/web — Next.js]
    D -->|robot.urdf + meshes| SIM[packages/sim — three.js + Rapier]
    D -->|config.json| FW[packages/firmware — ESP32-S3]
    D -->|print_plan.json grams/time| PN[Print network]
    B[apps/web /builder — Blockly] -->|Behavior Script JSON| SIM
    B -->|HTTP POST| FW
    WEB --- SB[(Supabase: auth, Postgres, storage, pgvector)]
    WEB --- ST[Stripe + Stripe Connect]
    PN --- EP[EasyPost labels]
    SUP[AI support agent] --- SB
    APP[apps/web /drive + /play] <-->|WebSocket + HTTP §5.4| FW
    APP <-->|same protocol, in-page bridge| SIM
```

### 3.2 Component inventory

| Component | Path | Language | Purpose |
|---|---|---|---|
| Engine | `packages/engine` | Python 3.12 | Compiles manifests → all artifacts. CLI `botforge` |
| Module registry | `registry/modules/*.yaml` | YAML | Catalog of electronic modules (§5.1) |
| Robot definitions | `robots/<id>/` | YAML + Python part scripts + JSON | Per-robot data (§5.2) |
| Firmware | `packages/firmware` | C++ (Arduino core / PlatformIO) | Universal ESP32-S3 firmware + Behavior VM |
| Behavior lib | `packages/behavior-ts` | TypeScript | BSJ types, zod schema, reference interpreter |
| Simulator | `packages/sim` | TypeScript | three.js + Rapier physics, loads generated URDF |
| Shared types | `packages/shared` | TypeScript | Types generated from JSON Schemas |
| Web app | `apps/web` | Next.js 14 (App Router) | Site, catalog, builder, sim, drive, flasher, store, print network, admin |
| Docs site | `apps/docs` | Astro Starlight | Per-robot build guides (content generated by engine) |
| Infra | `infra/`, `.github/workflows/` | YAML/Docker | CI, engine container (includes PrusaSlicer CLI) |

### 3.3 Data flow (canonical build)

1. Author `robots/rover-v1/` data (once, by a human/agent designer).
2. `botforge build robots/rover-v1` → validates against registry, then runs generators: CAD → wiring → BOM → print plan → assembly renders → URDF → firmware config → docs MDX → catalog.json.
3. CI uploads `dist/rover-v1/` to Supabase Storage + attaches firmware binaries to a GitHub Release.
4. Web + docs consume artifacts. Sim loads the URDF. Flasher page serves the release binaries via ESP Web Tools.
5. Builder produces BSJ → runs in sim → same file POSTed to the physical robot.

---

## 4. MONOREPO & TOOLING

### 4.1 Repository layout

```
botforge/
├── apps/
│   ├── web/                  # Next.js 14, TS, Tailwind
│   └── docs/                 # Astro Starlight
├── packages/
│   ├── engine/               # Python (uv). Package botforge_engine, CLI `botforge`
│   ├── firmware/             # PlatformIO project
│   ├── behavior-ts/          # BSJ types + interpreter
│   ├── sim/                  # three.js + rapier world
│   └── shared/               # TS types generated from schemas
├── registry/
│   ├── modules/*.yaml        # §5.1
│   └── fasteners.yaml
├── robots/
│   ├── _test-min/            # tiny fixture robot for golden tests
│   └── rover-v1/             # first product robot
├── dist/                     # build output, gitignored (CI artifact)
├── infra/
│   ├── engine.Dockerfile     # python + cadquery + prusaslicer CLI + EGL
│   └── profiles/pla-0.20.ini # slicer profile
├── docs/                     # internal: DECISIONS.md, BACKLOG.md, reports/
├── .github/workflows/ci.yml
├── turbo.json  package.json  pnpm-workspace.yaml
└── PLAN.md                   # this file
```

### 4.2 Fixed stack (do not substitute — see rule 8)

| Area | Choice | Why |
|---|---|---|
| JS workspace | pnpm 9 + Turborepo, TypeScript 5, Node 20 | Standard, fast, well-known |
| Web | Next.js 14 App Router + Tailwind, deployed on Vercel | Solo-founder default, huge training coverage |
| Backend | Supabase (Auth, Postgres + RLS, Storage, pgvector, Edge Functions) | One vendor for auth/db/files/vectors |
| Payments | Stripe (Checkout, Billing, Tax) + Stripe Connect Express (printer payouts) | Handles global tax + marketplace payouts |
| Shipping labels | EasyPost | One API, many carriers |
| Email | Resend | Simple transactional email |
| Analytics | Plausible | Privacy-friendly, zero-config |
| Python | 3.12 + uv + pydantic v2 + typer + Jinja2 | Engine stack |
| CAD | CadQuery 2.4 (code-driven parametric CAD) | Scriptable, exports STL/STEP/3MF |
| Mesh QC / render | trimesh + pyrender (offscreen EGL) | Headless assembly renders |
| Wiring diagrams | WireViz | YAML → SVG harness diagrams + wire BOM |
| Slicing estimates | PrusaSlicer CLI (in engine Docker image) | Grams + minutes per part → auto print pricing |
| Blocks | Blockly 11 | The standard for block programming |
| Sim | three.js + @dimforge/rapier3d-compat + urdf-loader | Browser physics, WASM, deterministic stepping |
| Firmware | PlatformIO, arduino-esp32 core 3.x, ESP32-S3 (devkit: ESP32-S3-DevKitC-1 N8R2), ArduinoJson 7, LittleFS | Easiest robust path; native USB |
| Browser flashing | ESP Web Tools (esptool-js) | Flash from Chrome, zero installs for users |
| Tests | vitest, pytest, `pio test` (native env), Playwright | Per-layer testing |
| Errors/monitoring | Sentry + UptimeRobot | Sleep-safe ops |

### 4.3 Root commands (wire these up in Phase 0)

| Command | Does |
|---|---|
| `pnpm dev` | Runs web + docs dev servers (turbo) |
| `pnpm test` | All JS tests |
| `pnpm build` | Builds all JS apps/packages |
| `uv run botforge validate robots/rover-v1` | Schema + registry validation |
| `uv run botforge build robots/rover-v1 [--only cad,wiring,...]` | Full artifact build → `dist/` |
| `pnpm fw:build` | PlatformIO build (wraps `pio run` in packages/firmware) |
| `pnpm fw:test` | Behavior VM native tests (`pio test -e native`) |
| `pnpm e2e` | Playwright suite |

### 4.4 CI (GitHub Actions, single `ci.yml`)

Jobs: `lint` (eslint/prettier/ruff) → `test-js` → `test-py` → `engine-build` (runs `botforge build` for `_test-min` + `rover-v1` inside `infra/engine.Dockerfile`, asserts goldens, uploads `dist/` artifact) → `firmware-build` (pio, uploads merged `firmware-merged.bin` + `esp-web-tools-manifest.json`) → `web-build`. On tags `v*`: attach firmware binaries to a GitHub Release; sync `dist/` to Supabase Storage; Vercel deploys web+docs from main.

---

## 5. CORE CONTRACTS (frozen — see rule 3)

These five specifications are the interfaces between every part of the system. Implement them exactly.

### 5.1 Module Registry — `registry/modules/<id>.yaml`

One YAML file per electronic module. Fields:

| Field | Type | Notes |
|---|---|---|
| `id` | str | kebab-case, unique |
| `name` | str | Human name |
| `category` | enum | `core` \| `power` \| `actuator` \| `sensor` \| `output` \| `input` \| `passive` |
| `electrical.vcc` | str | e.g. `"3.0-10.8V"` |
| `electrical.logic_v` | num | 3.3 |
| `electrical.current_ma` | {typ, max} | For power budget check |
| `electrical.pins[]` | list | `{name, type, required}` — type ∈ `gpio, pwm, adc, i2c_sda, i2c_scl, 5v, 3v3, gnd, vbat` |
| `firmware.driver` | str | C++ class name the universal firmware instantiates |
| `firmware.params` | dict | Default driver params (JSON-schema-lite; engine copies into config.json) |
| `mech` | dict | `{dims_mm:[x,y,z], mass_g, mount:{pattern, screws}}` — pattern is a named cadlib helper, e.g. `sg90_pocket` |
| `wiring` | dict | `{connector, pinout:[...], wire_colors:{...}}` — feeds WireViz |
| `sourcing[]` | list | `{vendor, label, url, price_usd, affiliate_key}` — multiple vendors per module |
| `docs` | dict | `{blurb, datasheet_url, troubleshooting:[{symptom, fix}]}` — troubleshooting snippets are compiled into robot docs |
| `sim` | dict | Hints: `{kind: tof_raycast|line_ir|motor_dc|servo|led|buzzer|imu, ...}` |

**Launch module set (author all 12 in Phase 1):**

| id | driver | Notes | ~USD |
|---|---|---|---|
| `core-esp32s3-devkit` | `CoreS3Devkit` | ESP32-S3-DevKitC-1 N8R2; exposes gpio map | 8.00 |
| `pwr-1s-boost` | `PowerMon` | 18650/1S Li-ion charger+5V boost shield (USB-C). Battery NOT included/shipped | 2.50 |
| `motor-n20` | — (driven via drv-8833) | N20 metal-gear 6V 150RPM | 3.00 |
| `drv-8833` | `Motor_DRV8833` | Dual H-bridge breakout | 1.50 |
| `servo-sg90` | `Servo_Std` | 9g 180° | 2.00 |
| `servo-mg90s` | `Servo_Std` | Metal-gear 9g | 3.50 |
| `sens-vl53l0x` | `Range_VL53L0X` | I2C time-of-flight, 2m | 2.50 |
| `sens-line-2ch` | `Line_TCRT` | 2× TCRT5000 analog line sensors | 1.50 |
| `led-ws2812-2` | `Pixel_WS2812` | 2-pixel "eyes" stick | 0.50 |
| `buzzer-passive` | `Buzzer_PWM` | Passive piezo | 0.30 |
| `sw-slide` | — (passive) | Power switch | 0.20 |
| `imu-mpu6050` | `IMU_6050` | Deferred to Phase 6 robots | 2.00 |

**Full example — `registry/modules/drv-8833.yaml`:**

```yaml
id: drv-8833
name: DRV8833 dual motor driver
category: actuator
electrical:
  vcc: "2.7-10.8V"
  logic_v: 3.3
  current_ma: { typ: 400, max: 1500 }
  pins:
    - { name: vcc,  type: 5v,   required: true }
    - { name: gnd,  type: gnd,  required: true }
    - { name: ain1, type: pwm,  required: true }
    - { name: ain2, type: pwm,  required: true }
    - { name: bin1, type: pwm,  required: true }
    - { name: bin2, type: pwm,  required: true }
    - { name: slp,  type: gpio, required: false }
firmware:
  driver: Motor_DRV8833
  params: { pwm_hz: 20000, slew_per_s: 400 }
mech:
  dims_mm: [20, 15, 3]
  mass_g: 2
  mount: { pattern: pcb_m2_2hole_15mm, screws: m2x6_selftap }
wiring:
  connector: dupont_2_54
  wire_colors: { vcc: red, gnd: black, ain1: yellow, ain2: orange, bin1: green, bin2: blue, slp: white }
sourcing:
  - { vendor: aliexpress, label: "DRV8833 module", url: "https://www.aliexpress.com/w/wholesale-drv8833.html", price_usd: 1.50, affiliate_key: ali }
  - { vendor: amazon, label: "DRV8833 (3-pack)", url: "https://www.amazon.com/s?k=drv8833", price_usd: 7.99, affiliate_key: amz }
docs:
  blurb: Drives both wheel motors. Tiny H-bridge chip on a breakout board.
  datasheet_url: https://www.ti.com/lit/ds/symlink/drv8833.pdf
  troubleshooting:
    - { symptom: "One wheel spins the wrong way", fix: "Swap that motor's two wires at the driver, or flip its +/- in the builder's motor settings." }
    - { symptom: "Motors twitch or robot reboots when driving", fix: "Battery is low or wires too thin — charge the cell and check the 5V/GND wires are seated." }
sim:
  kind: motor_dc
```

**Second example — `registry/modules/servo-sg90.yaml`:**

```yaml
id: servo-sg90
name: SG90 micro servo
category: actuator
electrical:
  vcc: "4.0-6.0V"
  logic_v: 3.3
  current_ma: { typ: 150, max: 700 }
  pins:
    - { name: vcc, type: 5v,  required: true }
    - { name: gnd, type: gnd, required: true }
    - { name: sig, type: pwm, required: true }
firmware:
  driver: Servo_Std
  params: { min_us: 500, max_us: 2400, deg_min: 0, deg_max: 180, attach_stagger_ms: 60 }
mech:
  dims_mm: [23, 12.2, 29]
  mass_g: 9
  mount: { pattern: sg90_pocket, screws: m2x8_selftap }
wiring:
  connector: servo_3pin
  wire_colors: { vcc: red, gnd: brown, sig: orange }
sourcing:
  - { vendor: aliexpress, label: "SG90 servo", url: "https://www.aliexpress.com/w/wholesale-sg90.html", price_usd: 2.00, affiliate_key: ali }
docs:
  blurb: Small hobby servo, rotates 0–180°.
  datasheet_url: ""
  troubleshooting:
    - { symptom: "Servo buzzes at rest", fix: "Normal under light load; if hot, check nothing is jamming the horn." }
sim:
  kind: servo
```

Also create `registry/fasteners.yaml`: entries `{id, name, spec, sourcing[]}` for `m2x6_selftap`, `m2x8_selftap`, `m2_heatinsert_optional`, `m3_ball_6mm` (caster ball).

### 5.2 Robot Manifest — `robots/<id>/robot.yaml` (+ `assembly.yaml`, `parts/*.py`, `behaviors/*.json`)

| Field | Notes |
|---|---|
| `schema_version` | `1` |
| `robot: {id, name, tagline, version, size_class, difficulty, est_build_minutes, hero_color}` | `size_class: palm`, `difficulty: beginner` for rover |
| `modules[]` | Instances: `{id, ref, label}` — `ref` points at registry id; `id` is instance id (e.g. `motor_left`) |
| `connections[]` | Electrical edges: `{from: <inst>.<pin>, to: <inst>.<pin>, len_mm, note?}`. **This is the single source for the wiring diagram AND the firmware pin config** (P1). Core pins are `core.gpioN`, power pins `pwr.5v`/`pwr.gnd` |
| `printed_parts[]` | `{id, script, params{}, qty, material, color_role}` — `script` is a file in `parts/` exposing `build(params) -> cq.Workplane` |
| `fasteners[]` | `{ref, qty}` from `registry/fasteners.yaml` |
| `assembly` | `"assembly.yaml"` |
| `behaviors[]` | `{id, file, default?}` |
| `firmware: {autostart_behavior}` | |
| `sim: {drive: diff, wheel_radius_mm, track_mm, arena_default}` | Kinematics hints for the sim |
| `options[]` | Phase 6 configurator: optional module slots `{slot, ref, adds_connections[], adds_parts[]}` |

**Complete first robot — `robots/rover-v1/robot.yaml`:**

```yaml
schema_version: 1
robot:
  id: rover-v1
  name: Rover
  tagline: A palm-sized explorer that dodges obstacles and follows lines.
  version: 1.0.0
  size_class: palm
  difficulty: beginner
  est_build_minutes: 90
  hero_color: "#ff6b35"

modules:
  - { id: core,        ref: core-esp32s3-devkit, label: Brain }
  - { id: pwr,         ref: pwr-1s-boost,        label: Power }
  - { id: mdrv,        ref: drv-8833,            label: Motor driver }
  - { id: motor_left,  ref: motor-n20,           label: Left motor }
  - { id: motor_right, ref: motor-n20,           label: Right motor }
  - { id: range,       ref: sens-vl53l0x,        label: Distance eye }
  - { id: line,        ref: sens-line-2ch,       label: Line sensors }
  - { id: eyes,        ref: led-ws2812-2,        label: LED eyes }
  - { id: buzz,        ref: buzzer-passive,      label: Beeper }
  - { id: sw,          ref: sw-slide,            label: Power switch }

connections:
  # power tree
  - { from: pwr.5v,  to: core.5v,  len_mm: 60 }
  - { from: pwr.gnd, to: core.gnd, len_mm: 60 }
  - { from: pwr.5v,  to: mdrv.vcc, len_mm: 50 }
  - { from: pwr.gnd, to: mdrv.gnd, len_mm: 50 }
  - { from: sw.a,    to: pwr.out_switch_a, len_mm: 40, note: switch inline on boost output }
  - { from: sw.b,    to: pwr.out_switch_b, len_mm: 40 }
  # motor driver signals
  - { from: core.gpio4, to: mdrv.ain1, len_mm: 70 }
  - { from: core.gpio5, to: mdrv.ain2, len_mm: 70 }
  - { from: core.gpio6, to: mdrv.bin1, len_mm: 70 }
  - { from: core.gpio7, to: mdrv.bin2, len_mm: 70 }
  - { from: core.gpio15, to: mdrv.slp, len_mm: 70 }
  # motors
  - { from: mdrv.aout1, to: motor_left.m1,  len_mm: 55 }
  - { from: mdrv.aout2, to: motor_left.m2,  len_mm: 55 }
  - { from: mdrv.bout1, to: motor_right.m1, len_mm: 55 }
  - { from: mdrv.bout2, to: motor_right.m2, len_mm: 55 }
  # ToF (I2C)
  - { from: core.gpio8, to: range.sda, len_mm: 80 }
  - { from: core.gpio9, to: range.scl, len_mm: 80 }
  - { from: core.3v3,   to: range.vcc, len_mm: 80 }
  - { from: core.gnd,   to: range.gnd, len_mm: 80 }
  # line sensors (ADC1 pins)
  - { from: core.gpio1, to: line.out_l, len_mm: 90 }
  - { from: core.gpio2, to: line.out_r, len_mm: 90 }
  - { from: core.3v3,   to: line.vcc,   len_mm: 90 }
  - { from: core.gnd,   to: line.gnd,   len_mm: 90 }
  # eyes + buzzer
  - { from: core.gpio38, to: eyes.din, len_mm: 100 }
  - { from: core.5v,     to: eyes.vcc, len_mm: 100 }
  - { from: core.gnd,    to: eyes.gnd, len_mm: 100 }
  - { from: core.gpio16, to: buzz.sig, len_mm: 60 }
  - { from: core.gnd,    to: buzz.gnd, len_mm: 60 }

printed_parts:
  - { id: chassis,     script: chassis.py,     params: { l: 96, w: 74, wall: 2.0 }, qty: 1, material: PLA, color_role: body }
  - { id: wheel,       script: wheel.py,       params: { d: 42, tire_grooves: 8 },  qty: 2, material: PLA, color_role: accent }
  - { id: caster_mount,script: caster.py,      params: { ball_d: 6.2 },             qty: 1, material: PLA, color_role: body }
  - { id: head,        script: head.py,        params: {},                          qty: 1, material: PLA, color_role: accent }
  - { id: lid,         script: lid.py,         params: {},                          qty: 1, material: PLA, color_role: body }

fasteners:
  - { ref: m2x6_selftap, qty: 8 }
  - { ref: m2x8_selftap, qty: 4 }
  - { ref: m3_ball_6mm,  qty: 1 }

assembly: assembly.yaml

behaviors:
  - { id: avoid,  file: behaviors/avoid_obstacles.json, default: true }
  - { id: follow, file: behaviors/line_follow.json }
  - { id: pet,    file: behaviors/pet_mode.json }

firmware:
  autostart_behavior: avoid

sim:
  drive: diff
  wheel_radius_mm: 21
  track_mm: 82
  arena_default: obstacle_pen
```

**`robots/<id>/assembly.yaml`** — poses + LEGO-style steps:

```yaml
poses:            # final pose of every part/module in chassis frame, mm + deg
  chassis:     { xyz: [0, 0, 0],    rpy: [0, 0, 0] }
  motor_left:  { xyz: [-28, 30, 8], rpy: [0, 0, 90],  explode: [0, 40, 0] }
  motor_right: { xyz: [-28, -30, 8],rpy: [0, 0, -90], explode: [0, -40, 0] }
  wheel@1:     { xyz: [-28, 44, 8], rpy: [90, 0, 0],  explode: [0, 35, 0] }
  wheel@2:     { xyz: [-28, -44, 8],rpy: [-90, 0, 0], explode: [0, -35, 0] }
  caster_mount:{ xyz: [38, 0, 2],   rpy: [0, 0, 0],   explode: [0, 0, -25] }
  # ... every part + module gets a pose (TUNE against first physical print 🧍)
steps:
  - { id: 1,  title: Print check,          adds: [],                       note: Confirm all printed parts against the print guide. }
  - { id: 2,  title: Fit the left motor,   adds: [motor_left],  fasteners: [m2x8_selftap x2], note: Wires face inward. }
  - { id: 3,  title: Fit the right motor,  adds: [motor_right], fasteners: [m2x8_selftap x2], note: Mirror of step 2. }
  - { id: 4,  title: Caster ball,          adds: [caster_mount, m3_ball_6mm], fasteners: [m2x6_selftap x2] }
  - { id: 5,  title: Motor driver,         adds: [mdrv],        fasteners: [m2x6_selftap x2] }
  - { id: 6,  title: Power board + switch, adds: [pwr, sw] }
  - { id: 7,  title: The brain,            adds: [core],        note: USB port faces the rear cutout. }
  - { id: 8,  title: Wire it up,           adds: [],            note: Follow the wiring diagram page — colors match. }
  - { id: 9,  title: Sensors on the head,  adds: [range, eyes, head] }
  - { id: 10, title: Line sensors + lid,   adds: [line, buzz, lid, wheel@1, wheel@2], fasteners: [m2x6_selftap x2] }
```

Renderer contract: for step N, all parts from steps < N are drawn ghosted grey; parts added in step N are drawn in theme color, offset along their `explode` vector, with the vector drawn as an arrow. `@n` suffix addresses instances of qty>1 parts.

### 5.3 Behavior Script JSON (BSJ) v1 — the one program format (P3)

A **statement tree**, not a free graph — trivially serialised from Blockly, trivially interpreted in C++ and TS.

```json
{
  "bsj": 1,
  "name": "avoid_obstacles",
  "vars": [{ "name": "mood", "init": 0 }],
  "handlers": [
    { "event": { "type": "on_start" }, "body": [ /* Stmt[] */ ] },
    { "event": { "type": "on_tick", "ms": 100 }, "body": [ /* Stmt[] */ ] }
  ]
}
```

`Stmt = { "op": string, ...params, "body"?: Stmt[], "else"?: Stmt[] }`. `Expr` = number | `{"sensor": "<inst>.<field>"}` | `{"var": "name"}` | `{"rand": [min,max]}` | `{"cmp": [Expr, "<|<=|>|>=|==|!=", Expr]}` | `{"math": [Expr, "+|-|*|/|min|max", Expr]}` | `{"logic": ["and|or", Expr, Expr]}` | `{"not": Expr}` | `{"call": "battery_pct"|"elapsed_ms"}`.

**Ops (complete v1 set — do not add more without a DECISIONS entry):**

| op | params | Notes |
|---|---|---|
| `drive` | `l, r` (−100..100) | Sets wheel power, returns immediately |
| `drive_time` | `l, r, ms` | Non-blocking wait, then stop |
| `stop` | — | |
| `servo` | `id, deg` | |
| `servo_sweep` | `id, from, to, ms` | Non-blocking interpolation |
| `led` | `r, g, b, id?` | id omitted = all pixels |
| `led_off` | `id?` | |
| `tone` | `hz, ms` | |
| `wait` | `ms` | Non-blocking |
| `set_var` / `change_var` | `name, value:Expr` | |
| `if` | `cond:Expr` + `body` + optional `else` | |
| `repeat` | `n` + `body` | |
| `while` | `cond` + `body` | |
| `forever` | `body` | |
| `break` | — | Exits innermost loop |
| `log` | `msg` | → WS `log` message / sim console |

**Events:** `on_start`, `on_tick {ms}`, `on_button` (BOOT button). **Sensor fields:** `range.mm`, `line.l`, `line.r` (0–4095), `imu.pitch|roll` (Phase 6).

**Execution semantics (both interpreters):** each handler is an independent stack machine (frames of `{stmts, index, state}` — implement waits as stored deadlines, NOT threads/coroutines). Scheduler ticks at 50 Hz; ≤ 4 concurrent handler activations (an `on_tick` firing while its previous activation still runs is skipped); ≤ 200 ops per handler per tick (runaway guard); runtime error ⇒ stop motors, emit `log level=error`, halt behavior. Limits: ≤ 128 statements, ≤ 8 vars, file ≤ 16 KB. The C++ and TS interpreters must pass the **same golden trace tests** (§ Phase 3).

### 5.4 Connectivity & protocol

**Provisioning:** first boot → SoftAP `Botforge-XXXX` (XXXX from MAC) → captive portal (tiny vanilla HTML from LittleFS) → user picks Wi-Fi + name → STA join → mDNS `botforge-xxxx.local`. 3 failed joins ⇒ back to AP. Hold BOOT 5 s ⇒ wipe Wi-Fi creds.

**HTTP (port 80):** `GET /api/info` → `{fw, robot_id, name, cfg_hash, ip}` · `GET|PUT /api/config` (config.json) · `POST /api/behavior` (BSJ ≤16 KB → saved to LittleFS) · `POST /api/behavior/ctl` `{action: run|stop|autostart_on|autostart_off}` · `POST /api/ota` (firmware.bin) · `GET /api/logs` (ring buffer).

**WebSocket (port 81, path `/ws`), JSON messages:**

| Direction | `t` | Payload |
|---|---|---|
| →robot | `hello` | `{}` |
| →robot | `ping` | every 500 ms from app |
| →robot | `mode` | `{mode: "manual"\|"behavior"}` |
| →robot | `cmd.drive` | `{l, r}` |
| →robot | `cmd.servo` | `{id, deg}` |
| →robot | `cmd.led` / `cmd.tone` | as BSJ params |
| robot→ | `hello.ack` | `{fw, robot_id, name, cfg_hash}` |
| robot→ | `telemetry` (5 Hz) | `{batt_mv, rssi, mode, behavior_running, sensors: {range:{mm}, line:{l,r}, ...}}` |
| robot→ | `log` | `{level, msg}` |

**Safety:** in `manual` mode, motors stop if no `cmd.*`/`ping` received for 800 ms (deadman). `behavior` mode is unaffected (P8 — robot runs without any connection).

**The simulator implements this exact message set** over an in-page bridge (EventTarget), so `/drive` and `/play` use one transport interface (`RobotLink`) with two impls: `WsLink(host)` and `SimLink(world)`.

### 5.5 Generated firmware config — `dist/<robot>/firmware/config.json`

Derived entirely from `robot.yaml` connections (P1, P2):

```json
{
  "cfg": 1,
  "robot_id": "rover-v1",
  "name_default": "Rover",
  "autostart": "avoid",
  "modules": [
    { "id": "mdrv", "driver": "Motor_DRV8833",
      "pins": { "ain1": 4, "ain2": 5, "bin1": 6, "bin2": 7, "slp": 15 },
      "params": { "pwm_hz": 20000, "slew_per_s": 400 } },
    { "id": "range", "driver": "Range_VL53L0X", "pins": { "sda": 8, "scl": 9 }, "params": {} },
    { "id": "line",  "driver": "Line_TCRT",     "pins": { "l": 1, "r": 2 },    "params": {} },
    { "id": "eyes",  "driver": "Pixel_WS2812",  "pins": { "din": 38 }, "params": { "count": 2 } },
    { "id": "buzz",  "driver": "Buzzer_PWM",    "pins": { "sig": 16 }, "params": {} },
    { "id": "pwr",   "driver": "PowerMon",      "pins": {}, "params": { "vbat_adc": null } }
  ]
}
```

`cfg_hash` = first 8 hex chars of sha256(file). Firmware maps `driver` strings to constructors via a static factory table.

### 5.6 Build output layout — `dist/<robot_id>/`

```
manifest.resolved.json      # manifest with registry data inlined
catalog.json                # card data for the website (name, tagline, imgs, cost est, difficulty)
cad/stl/*.stl  cad/step/*.step  cad/3mf/*.3mf
print/print_plan.json      # per part: grams, minutes, settings profile, plate hints
wiring/harness.yaml  wiring/wiring.svg  wiring/wiring.png  wiring/wire_bom.csv
bom/bom.json  bom/bom.csv  bom/bom.md            # electronics + fasteners + printed, with sourcing links
assembly/steps.json  assembly/step-01.png ... step-NN.png
urdf/robot.urdf  urdf/meshes/*.stl
firmware/config.json
behaviors/*.json
docs/                       # MDX bundle consumed by apps/docs
```

---

## PHASE 0 — Repo scaffold & tooling (≈1 week)

**Objective:** empty-but-runnable monorepo with CI, matching §4 exactly.

**Tasks**
1. Init pnpm workspace + Turborepo; scaffold `apps/web` (Next 14 + Tailwind + TS), `apps/docs` (Astro Starlight), empty `packages/{behavior-ts,sim,shared}` with vitest configured.
2. Scaffold `packages/engine` with uv: pydantic v2, typer CLI stub (`botforge --help`), pytest, ruff.
3. Scaffold `packages/firmware`: PlatformIO project, envs `esp32s3` (board `esp32-s3-devkitc-1`, arduino core 3.x, LittleFS partition + OTA partitions) and `native` (for VM unit tests). `pio run` must succeed with a blink `main.cpp`.
4. `infra/engine.Dockerfile`: python:3.12 + uv + CadQuery + trimesh + pyrender + EGL libs + WireViz + PrusaSlicer CLI (AppImage extracted). Verify all imports and `prusa-slicer --help` in container.
5. `.github/workflows/ci.yml` per §4.4 (jobs may be mostly no-op initially but the pipeline shape exists).
6. Licensing files (see §D): root `LICENSE-CODE.md` (proprietary, all rights reserved) — `packages/firmware/LICENSE` = GPL-3.0 — `robots/` and `registry/` `LICENSE` = CC BY-NC-SA 4.0 notice.
7. Create `docs/DECISIONS.md`, `docs/BACKLOG.md`, `docs/reports/`, root `README.md` (how to run everything), `.env.example`.
8. Prettier/eslint/ruff configs; pre-commit via husky + lint-staged.

**Acceptance** ▢ `pnpm build`, `pnpm test`, `uv run botforge --help`, `pio run` all green locally and in CI ▢ Docker engine image builds in CI ▢ README verified by running on a clean clone.

---

## PHASE 1 — The Engine + Rover generated end-to-end (≈3–4 weeks) ← the moat

**Objective:** `uv run botforge build robots/rover-v1` produces the complete §5.6 output. This phase is the heart of the business; take the time to make it clean.

**Tasks**
1. **Models:** pydantic models mirroring §5.1/§5.2 exactly (`botforge_engine/models/`). Validation errors must be human-friendly (path + message), because robot authors are the customer of these errors.
2. **Registry loader** + `botforge validate <robot>`: checks refs exist, required pins connected, no GPIO double-booked, ADC-only pins used for adc types, power budget (Σ current_ma.max ≤ boost rating 2000 mA ⇒ warn), connection endpoints are legal pin types.
3. **cadlib** (`botforge_engine/cadlib/`): shared CadQuery helpers — `plate()`, `boss_m2_selftap()` (Ø1.7 pilot), `pocket_sg90()`, `clamp_n20()`, `pocket_pcb(dims, standoff)`, `wire_channel()`, `snapless_lip()`; constants `FIT=0.20`, `WALL_MIN=1.6`. Rule: **all parts print support-free** (≤45° overhangs; chamfer, don't fillet, downward faces). Document conventions in `packages/engine/CAD_GUIDE.md`.
4. **Rover part scripts** (`robots/rover-v1/parts/*.py`): chassis (tray with motor clamps, PCB pockets, rear USB cutout, front head mount), wheel (press-fit N20 D-shaft hub + grooved tire surface), caster_mount (6 mm ball socket), head (VL53L0X window + WS2812 eye holes, angled 10°), lid (clips over tray with screw bosses). Each exposes `build(params) -> cq.Workplane`.
5. **CAD generator:** exports STL (linear tol 0.05 mm)/STEP/3MF per part×qty; QC via trimesh: watertight, volume > 0, bbox within declared envelope, overhang report (% faces steeper than 50° facing down ⇒ warn).
6. **Print plan generator:** run PrusaSlicer CLI with `infra/profiles/pla-0.20.ini` (0.2 mm, 3 walls, 15% gyroid, no supports) per STL; parse `; filament used [g]` and estimated time from gcode comments → `print_plan.json`. If slicer binary missing locally, skip with warning (CI always has it).
7. **Wiring generator:** manifest connections → WireViz YAML (connector defs from module `wiring`, wire colors from module color maps, lengths from `len_mm`) → `wiring.svg/png` + `wire_bom.csv`. Group by connector; label every wire `FROM→TO`.
8. **BOM generator:** electronics (from modules×sourcing, cheapest vendor as primary + alternates), fasteners, printed parts (with grams from print plan), estimated totals → `bom.{json,csv,md}`. Sourcing URLs pass through the affiliate redirect scheme `https://SITE/out/{affiliate_key}/{module_id}` (Phase 4 implements the redirect; generator emits final URLs now).
9. **Assembly generator:** load poses+steps (§5.2), render per-step PNG 1600×1200 with pyrender offscreen (isometric cam, ghost grey prior parts, theme-colored new parts offset by `explode`, arrow lines along explode vectors), captions from step notes → `steps.json` + images.
10. **URDF generator:** `chassis`=base_link; wheels = continuous joints (axis from pose); servo modules = revolute joints with limits from registry; sensor modules = fixed links at their poses (sim raycasts from these frames); masses = trimesh volume × 1.24 g/cm³ for prints, `mass_g` for modules; meshes referenced from `urdf/meshes/`.
11. **Firmware config generator** per §5.5 (pure function of connections + registry driver params).
12. **Docs generator:** Jinja2 MDX templates → `dist/<id>/docs/`: `index`, `safety`, `source-parts` (BOM tables + links), `print-guide` (per-part settings + grams), `wiring` (embeds SVG + wire table), `assemble` (one section per step, image + note + fasteners), `flash`, `first-run` (provisioning + drive), `play` (builder link), `troubleshooting` (compiled from module troubleshooting snippets). A small sync script copies the bundle into `apps/docs/src/content/robots/<id>/`.
13. **catalog.json generator** (name, tagline, hero step image, difficulty, est cost from BOM, est print grams/time, links).
14. **CLI orchestrator** `botforge build <path> [--only ...]` + `botforge clean`.
15. **Fixture robot** `robots/_test-min` (core + eyes + buzz only, 1 printed plate, 2 steps) with **committed golden outputs** (hashes for binary files, full text for JSON/YAML/CSV). Rover gets snapshot hashes with a `--update-goldens` flag. Golden tests run in CI inside the engine container.

**Acceptance** ▢ `botforge validate` catches: bad ref, missing required pin, double-booked GPIO, ADC misuse (add 4 negative tests) ▢ full rover build < 10 min in CI, produces every §5.6 file ▢ goldens green ▢ all rover parts watertight + support-free report clean ▢ total rover print estimate sanity: 60–180 g ▢ `apps/docs` renders the rover guide locally with images ▢ 🧍 Lewis reviews step renders + STLs (visual sanity; poses marked TUNE may be adjusted — that's data-only).

---

## PHASE 2 — Universal firmware + browser flashing + drive app (≈3 weeks)

**Objective:** flash a real ESP32-S3 from Chrome, provision Wi-Fi, drive the (bench-wired) rover from a phone, run a BSJ behavior on-device.

**🧍 Buy dev hardware first (~£30):** 1× ESP32-S3-DevKitC-1 N8R2, 1× DRV8833 board, 2× N20 6V 150RPM, 1× VL53L0X, 1× 2ch TCRT5000, WS2812 stick, passive buzzer, 1S 18650 USB-C boost shield + 18650 cell (local), jumper wires. (This is also Appendix C's shopping list.)

**Firmware structure (`packages/firmware/src/`):**
```
main.cpp                    # boot: LittleFS → Config → Net → drivers → VM → servers
core/{Config,Log,Net,HttpApi,WsServer,Ota}.{h,cpp}
drivers/IModule.h           # begin(cfg), tick(now_ms), read(field)->float, act(op,params)
drivers/{Motor_DRV8833, Servo_Std, Range_VL53L0X, Line_TCRT, Pixel_WS2812, Buzzer_PWM, PowerMon}.{h,cpp}
drivers/Factory.cpp         # string -> constructor table (P2)
vm/{Bsj.h, Vm.h, Vm.cpp}    # ArduinoJson parse into flat arrays; stack-machine per §5.3
data/portal/index.html      # provisioning captive portal (vanilla JS, <15KB)
```

**Tasks**
1. Config load/save (LittleFS `/config.json`, `/behavior.json`, `/wifi.json`); factory boot-button reset (hold 5 s).
2. Drivers for the 7 launch classes. Libraries: ESP32Servo, Pololu VL53L0X, Adafruit NeoPixel; motors + buzzer via LEDC directly. Motor slew limiting (`slew_per_s`) and staggered servo attach (`attach_stagger_ms`) built in — this prevents the classic brownout support tickets.
3. **Behavior VM** exactly per §5.3, `float` math, zero heap allocation after load (fixed pools: 128 stmts, 8 vars, 4 activations × 16-deep frames). Compile it for the `native` env with a mocked HAL and port the golden trace tests (shared JSON fixtures in `packages/behavior-ts/fixtures/` — same files test C++ and TS).
4. Provisioning per §5.4 (SoftAP + captive portal + mDNS). Portal shows robot name field + QR of `http://<name>.local`.
5. HTTP API + WS server per §5.4, telemetry at 5 Hz, manual-mode deadman 800 ms, log ring buffer (128 lines).
6. OTA: `POST /api/ota` (Update.h), and check-on-boot against GitHub Releases `latest.json` (optional flag in config).
7. CI: `pio run` artifacts → merged `firmware-merged.bin` (esptool merge_bin: bootloader+partitions+app+littlefs) + `esp-web-tools-manifest.json`; attach to Release on tags.
8. **Flasher page** `apps/web /flash`: ESP Web Tools button fed by the latest Release manifest, with a 3-step visual guide (plug USB → hold BOOT → flash).
9. **Drive page** `apps/web /drive`: `RobotLink` interface + `WsLink` impl; connect card (default `botforge-xxxx.local`, IP fallback — note iOS mDNS quirks in UI copy); virtual joystick (pointer events, no lib), servo sliders (from `/api/config`), telemetry bar (battery/RSSI/sensors), mode toggle, "upload behavior file" (POST + run).
10. Bench test protocol doc `docs/reports/PHASE-2-bench.md` for 🧍 Lewis: flash → provision → drive → sensors visible → upload `avoid_obstacles.json` → runs standalone with Wi-Fi off.

**Acceptance** ▢ VM native tests green (same fixtures as TS) ▢ firmware binary ≤ 1.6 MB, free heap > 100 KB after boot ▢ flash-from-Chrome works on a clean machine ▢ 🧍 bench protocol passes on real hardware ▢ deadman verified (kill app → motors stop ≤ 1 s) ▢ behavior survives reboot + runs with no Wi-Fi.

---

## PHASE 3 — No-code builder + simulator (≈3–4 weeks)

**Objective:** a kid-simple Blockly editor whose program runs in a physics sim in the browser and, unchanged, on the real robot.

**Tasks**
1. **`packages/behavior-ts`:** BSJ TypeScript types + zod schema + reference interpreter with injectable `RobotAdapter { drive, servo, led, tone, readSensor, log, now }`. Golden trace tests: run fixture programs against a scripted mock adapter, assert exact call sequences (fixtures shared with firmware — see Phase 2.3).
2. **Blockly builder** at `/builder`: one custom block per BSJ op/expr (≈26 blocks), toolbox categories **Events / Move / Sense / Light & Sound / Logic / Loops / Variables**; colors per category; custom generator Blockly→BSJ + loader BSJ→Blockly (round-trip test); zod-validate before export; save/load: localStorage + file download/upload (cloud saves are Phase 4 Pro); examples menu loads the rover's 3 shipped behaviors; live block-count/size meter (limits §5.3).
3. **`packages/sim`:** `SimWorld` — Rapier world (fixed step 1/120 s, seedable), loads `dist/<robot>/urdf` via urdf-loader onto three.js scene; differential-drive model (wheel power −100..100 → target angular velocity with torque cap + friction); servo joints as position motors; **virtual sensors**: ToF = raycast from sensor frame (σ = 2 mm noise, 2000 mm max), line = sample arena ground texture under each sensor point (0–4095), battery = simple discharge model. Arenas: `open_floor`, `line_oval` (SVG-textured line track), `obstacle_pen` (walled box + random blocks, seeded).
4. **`SimLink`** implementing the §5.4 message set (telemetry out, cmd/mode in) so `/drive` can drive the simulated robot with zero code changes.
5. **`/play` page:** split view — sim canvas (orbit camera, reset, arena picker, 1×/4× speed) + Blockly panel; ▶ Run in Sim / ⏹ / ⬆ Send to Robot (POST `/api/behavior` + ctl run to a connected `WsLink`). Console pane shows `log` messages from either link.
6. **Headless sim tests** (vitest, rapier WASM in Node): `avoid_obstacles` in `obstacle_pen` for 15 sim-seconds ⇒ displacement > 1 m and 0 sustained wall contacts; `line_follow` on `line_oval` ⇒ ≥ 60% lap progress. These become regression gates for engine URDF changes too.
7. Author rover's three behavior JSONs (`avoid_obstacles` — full text in Appendix B, `line_follow`, `pet_mode` — LEDs/beeps react to distance like a pet).

**Acceptance** ▢ round-trip Blockly↔BSJ lossless on all fixtures ▢ TS + C++ interpreters produce identical golden traces ▢ headless sim gates green in CI ▢ `/play` runs avoid-obstacles at 60 fps on a mid phone ▢ 🧍 Lewis sends a sim-built behavior to the real rover with one click and it behaves equivalently.

---

## PHASE 4 — Platform: site, accounts, downloads, Pro, affiliates (≈2–3 weeks)

**Objective:** the public product. Catalog, gated free downloads (email capture), Pro subscription, affiliate BOM links, generated docs live.

**🧍 Accounts to create with Lewis:** Supabase project, Stripe (test mode), Resend + domain DKIM, Plausible, Vercel, domain + brand name decision, Sentry.

**Site map:** `/` (landing) · `/robots` · `/robots/[id]` (hero renders, cost/print stats from catalog.json, Download files, Order printed parts → Phase 5, docs link) · `/play` · `/builder` · `/drive` · `/flash` · `/print-network` (two-sided landing) · `/pricing` · `/account` · `/admin` (role-gated) · `/legal/{terms,privacy,print-terms,refunds}` · docs on `docs.<domain>`.

**Tasks**
1. Apply Appendix A schema via Supabase migrations; RLS: users see/edit own rows; public read on `robots_catalog`; admin role via `profiles.role`.
2. Auth: email magic link + Google OAuth (Supabase). `/account`: profile, saved behaviors, subscription status, downloads history.
3. CI step: sync `dist/` → Supabase Storage bucket `artifacts/` (public-read for images, signed URLs for file bundles); upsert `robots_catalog` from each `catalog.json`.
4. Downloads: free but requires account → zips (`cad`, `full bundle`) served via signed URL; log to `downloads` (the email list + funnel metric).
5. **Pro:** Stripe Checkout (subscription, Stripe Tax on) + customer portal; webhook → `subscriptions`; entitlement flags in app. Pro gates at launch: cloud behavior saves (>3), premium sim arenas, OTA push from `/play` to a claimed robot, AI personality (Phase 7 feature, flag now), priority support tag.
6. **Affiliates:** `vendors` table (per-vendor URL templates/params) + `/out/[affiliate_key]/[module_id]` redirect route logging `affiliate_clicks` then 302 to the sourcing URL. Engine already emits these URLs (Phase 1.8).
7. Emails via Resend: welcome, receipt (Stripe handles its own), print-network events (Phase 5 hooks).
8. Docs deploy (Astro → Vercel, `docs.` subdomain); robot pages cross-link. OG images = hero assembly render.
9. Plausible events: download, flash_click, sim_run, send_to_robot, out_click, checkout_start. Sentry on web.
10. Playwright: signup → download; checkout (Stripe test clock) → entitlement visible.

**Acceptance** ▢ Lighthouse ≥ 90 on `/` and `/robots/rover-v1` ▢ e2e green ▢ Pro upgrade/downgrade reflects in ≤ 1 min ▢ affiliate redirect logs + 302s ▢ 🧍 Lewis approves copy + pricing before Stripe live mode.

---

## PHASE 5 — Print network marketplace (≈3 weeks)

**Objective:** a buyer with no printer orders the rover's printed parts; a certified nearby printer fulfils; we take 18%. Same-country matching only. Runs unattended except disputes.

**Order state machine (`print_requests.status`):**

| State | Actor/event → next |
|---|---|
| `draft` | buyer configures (robot, material=PLA, colors from `color_role` groups) → `open` |
| `open` | matching notifies ≤ 5 nearest certified printers (haversine on lat/lng) → first `accept` wins → `accepted`; 48 h no accept → widen radius; 96 h → `expired` + suggest fallback link-out (Craftcloud) |
| `accepted` | buyer pays quote (Stripe PaymentIntent, funds on platform) → `paid` |
| `paid` | printer prints, uploads ≥ 2 photos → AI QC pass (vision rubric: complete plate, no spaghetti/major stringing, matches part silhouettes) → `qc_passed`; fail → reprint or refund |
| `qc_passed` | platform buys EasyPost label (printer enters weight/dims, prefilled from print_plan + 15% + box preset), printer ships → `shipped` |
| `shipped` | carrier delivered → `delivered` |
| `delivered` | buyer approves or 72 h auto → `released` (Stripe Transfer to printer's Connect account, minus 18%) |
| any | dispute → `disputed` (admin queue 🧍) |

**Pricing (auto-quote, no negotiation at v1):** `quote = base 2.50 + grams × rate(material) × printer_multiplier + ship_estimate`, PLA rate 0.07 USD/g, printer sets multiplier 0.8–1.5. Grams come from `print_plan.json` (this is why Phase 1.6 matters). Display printer payout + platform fee transparently.

**Certification flow:** apply (printer model, materials, address → geocode via Mapbox 🧍 key, payout via Stripe Connect Express onboarding) → download `cert-coupon-v1` (engine-generated test part: overhang fan, bridge, tolerance pegs, embossed QR of application id) → upload 4 photos + self-measured peg dimensions → Claude vision + rubric auto-scores → pass ⇒ `certified` (first 3 real orders additionally flagged for buyer-approval QC) / borderline ⇒ admin review 🧍.

**Tasks**
1. Schema rows per Appendix A (`printers`, `printer_certs`, `print_requests`, `print_events` audit trail, `reviews`); RLS.
2. Buyer flow UI on `/robots/[id]` → order wizard → status page with timeline (from `print_events`).
3. Printer dashboard: applications, open jobs nearby, accept, photo upload, label purchase, earnings.
4. Matching + notifications (Resend) + expiry widening (Supabase scheduled Edge Function).
5. Stripe Connect Express onboarding + PaymentIntent + Transfer on release; webhooks drive state.
6. EasyPost integration (rate shop, label PDF, tracking webhook → `shipped`/`delivered`).
7. AI QC service: Edge Function calling Anthropic API with rubric + photos; store score + reasons.
8. `/admin`: dispute queue, cert review queue, manual state override, refund button.
9. Legal `/legal/print-terms` incl. the license grant: *certified printers receive a non-exclusive commercial license to fabricate platform designs solely to fulfil platform orders* (this is what makes NC licensing compatible with the network) 🧍 review.
10. Playwright e2e of the full happy path with Stripe test mode + EasyPost test keys.
11. 🧍 Seeding: recruit ~10 printers (maker Discords, r/3Dprinting, personal network) before public launch; model drafts the outreach posts.

**Acceptance** ▢ full e2e green ▢ money math verified (fee, transfer, refund paths) ▢ QC rubric tested against 10 good/10 bad sample photo sets (assemble from CC-licensed web images) ▢ unattended test: a staged order progresses overnight with zero human touches ▢ 🧍 live-mode dry run with one real printer.

---

## PHASE 6 — Robots #2 and #3 + configurator (≈2 weeks)

**Objective:** prove P1/P5 — two new robots ship with **zero engine/firmware/app code changes**, and buyers can customise robots.

**Tasks**
1. **`bip-v1`** — Otto-style biped: 4× `servo-sg90` (hips + ankles), ToF nose, eyes, buzzer. Parts: body, head, 2× leg, 2× foot. Behaviors: `walk` (tick-driven servo phase math using vars), `dance`, `avoid` (turn-in-place gait). Sim note: servo-legged walking in Rapier is acceptable-fidelity, not perfect — document expectation.
2. **`arm-v1`** — desktop arm: 4× `servo-mg90s` (base/shoulder/elbow/grip), base + 3 links + gripper parts. Behaviors: `wave`, `pick_demo`. Add `imu-mpu6050` registry module (driver `IMU_6050`) — this is a *registry+driver addition*, allowed; robot-specific code is not.
3. If any generator/firmware change is genuinely required, STOP, write the generalisation into DECISIONS.md, implement it as a general feature, then continue.
4. **Configurator v1:** manifest `options[]` (e.g. rover: add `imu`, add second ToF; bip: add grip hands) → UI toggles on robot page → server rebuild job: `build_jobs` table + worker (Fly.io machine or GitHub Actions `workflow_dispatch` runner using the engine container) → personalised bundle to Storage → email link. Target < 6 min.
5. Docs/catalog/print-network automatically pick up both robots (they must — that's the test).

**Acceptance** ▢ `git diff` for bip+arm touches only `robots/`, `registry/`, `drivers/IMU_6050`, fixtures ▢ both build green with goldens ▢ bip walks in sim ≥ 0.5 m/15 s ▢ configurator round-trip works ▢ 🧍 Lewis prints & builds bip (the fun checkpoint).

---

## PHASE 7 — AI support agent + launch (≈2 weeks)

**Objective:** support that scales like software, then go live.

**Tasks**
1. Ingestion: chunk `dist/*/docs` MDX (~800 tokens, robot-tagged) → embeddings → Supabase pgvector; re-ingest on CI artifact sync.
2. `/support` chat widget (site + docs): robot selector (or inferred from account), retrieval top-8, Anthropic API answer with system prompt (grounded-only, cite doc section links, safety: battery/soldering caution, never guess wiring — escalate instead).
3. Escalation: unresolved → `support_threads` + email Lewis with transcript; Pro users flagged priority.
4. Eval gate: `tests/support_eval.jsonl` — 30 real questions (wiring, brownouts, flashing, print settings, orders) with required key facts; CI scores ≥ 90% before deploy.
5. **Launch checklist** (all 🧍-approved): brand/domain final; legal pages (terms, privacy — UK/Gibraltar GDPR, print terms, digital refunds policy); Stripe live; Sentry + UptimeRobot + Supabase PITR backups verified; rate limiting on API routes; Discord community; content — build video (script drafted by model), Product Hunt + HN + r/robotics posts drafted; 10 seeded printers active; soft-launch to 20 beta builders; pricing live; support agent live; analytics goals firing.

**Acceptance** ▢ eval ≥ 90% ▢ agent refuses out-of-scope/dangerous confidently ▢ checklist 100% ▢ 🧍 GO decision.

---

## PHASE 8 — Post-launch, human-led: Core PCB v1 + kits (spec only here)

The agent drafts docs/schematic netlists; Lewis + a PCB contractor execute; JLCPCB fabricates/assembles/ships made-to-order (P6).

**Board goals:** replace devkit + boost + DRV8833 + jumper spaghetti with one board → assembly time halves, support tickets halve, margin appears.

**Spec:** ESP32-S3-WROOM-1-N8R2 · USB-C (native USB, USBLC6 ESD) · 1S Li-ion: MCP73871 charge + power-path, JST-PH 2.0 battery in, cell-voltage divider → ADC · TPS61088 boost (5 V ≥ 3 A peak) + 1000 µF bulk on servo rail · onboard DRV8833 + 2× JST-PH motor outs · 6× 3-pin servo headers (5 V rail) · 2× Qwiic (JST-SH I2C) · 4× JST-PH GPIO/ADC ports · 2× WS2812 onboard + chain out · buzzer · BOOT/RESET · power-switch pads · full pin map table to be frozen against firmware `CoreBoardV1` profile (a *config*, not a fork — P2). DFM: 4-layer, ≥0402, prefer JLC basic parts (verify LCSC stock at design time). Target < $9 landed @ 100 units, sell $24–29. RF compliance strategy: pre-certified WROOM module (CE/UKCA/FCC modular) → self-declaration for EMC; kit sold *without battery* keeps shipping simple. Kits at a 3PL only once demand is proven.

---

## APPENDIX A — Database schema (Supabase Postgres, apply as migration 0001)

```sql
create type sub_status as enum ('active','trialing','past_due','canceled');
create type print_status as enum ('draft','open','accepted','paid','printing','qc_passed','shipped','delivered','released','expired','disputed','refunded');
create type cert_status as enum ('applied','coupon_sent','review','certified','rejected','suspended');

create table profiles (
  id uuid primary key references auth.users,
  display_name text, role text not null default 'user',      -- 'user' | 'admin'
  country char(2), created_at timestamptz default now()
);
create table robots_catalog (
  id text primary key,                                        -- 'rover-v1'
  data jsonb not null, updated_at timestamptz default now()   -- catalog.json
);
create table downloads (
  id bigint generated always as identity primary key,
  user_id uuid references profiles, robot_id text references robots_catalog,
  bundle text, created_at timestamptz default now()
);
create table subscriptions (
  user_id uuid primary key references profiles,
  stripe_customer text, stripe_sub text, status sub_status, current_period_end timestamptz
);
create table saved_behaviors (
  id uuid primary key default gen_random_uuid(),
  user_id uuid references profiles, robot_id text, name text,
  bsj jsonb not null, updated_at timestamptz default now()
);
create table vendors ( key text primary key, name text, url_template text, notes text );
create table affiliate_clicks (
  id bigint generated always as identity primary key,
  vendor_key text references vendors, module_id text, user_id uuid, created_at timestamptz default now()
);
create table printers (
  id uuid primary key default gen_random_uuid(),
  user_id uuid references profiles, status cert_status not null default 'applied',
  printer_model text, materials text[], multiplier numeric(3,2) default 1.00,
  country char(2), lat double precision, lng double precision,
  stripe_connect_id text, rating numeric(3,2), jobs_done int default 0,
  created_at timestamptz default now()
);
create table printer_certs (
  id uuid primary key default gen_random_uuid(),
  printer_id uuid references printers, photos text[], measurements jsonb,
  ai_score numeric(4,2), ai_notes text, decided_by text, created_at timestamptz default now()
);
create table print_requests (
  id uuid primary key default gen_random_uuid(),
  buyer_id uuid references profiles, robot_id text references robots_catalog,
  parts jsonb not null,                 -- [{part_id, qty, color}]
  material text default 'PLA', country char(2), status print_status default 'draft',
  grams numeric, quote_cents int, ship_cents int, fee_cents int,
  printer_id uuid references printers, payment_intent text, transfer_id text,
  easypost_shipment text, tracking_url text,
  created_at timestamptz default now(), updated_at timestamptz default now()
);
create table print_events (             -- append-only audit trail
  id bigint generated always as identity primary key,
  request_id uuid references print_requests, actor text, event text, data jsonb,
  created_at timestamptz default now()
);
create table reviews (
  id uuid primary key default gen_random_uuid(),
  request_id uuid references print_requests, printer_id uuid references printers,
  buyer_id uuid references profiles, stars int check (stars between 1 and 5), body text,
  created_at timestamptz default now()
);
create table build_jobs (               -- configurator rebuilds
  id uuid primary key default gen_random_uuid(),
  user_id uuid, robot_id text, options jsonb, status text default 'queued',
  artifact_url text, created_at timestamptz default now()
);
create table support_threads (
  id uuid primary key default gen_random_uuid(),
  user_id uuid, robot_id text, status text default 'open', priority bool default false,
  created_at timestamptz default now()
);
create table support_messages (
  id bigint generated always as identity primary key,
  thread_id uuid references support_threads, role text, body text, created_at timestamptz default now()
);
create table doc_chunks (
  id bigint generated always as identity primary key,
  robot_id text, section text, url text, content text, embedding vector(1536)
);
-- RLS: enable on all; policies = owner-only rows via auth.uid(), public select on robots_catalog & vendors,
-- printers visible to owner + admins, print_requests visible to buyer + assigned printer + admins.
```

## APPENDIX B — `robots/rover-v1/behaviors/avoid_obstacles.json` (complete)

```json
{
  "bsj": 1,
  "name": "avoid_obstacles",
  "vars": [],
  "handlers": [
    { "event": { "type": "on_start" },
      "body": [
        { "op": "led", "r": 0, "g": 80, "b": 0 },
        { "op": "tone", "hz": 880, "ms": 120 },
        { "op": "wait", "ms": 150 },
        { "op": "tone", "hz": 1320, "ms": 120 }
      ] },
    { "event": { "type": "on_tick", "ms": 60 },
      "body": [
        { "op": "if", "cond": { "cmp": [ { "sensor": "range.mm" }, "<", 140 ] },
          "body": [
            { "op": "led", "r": 120, "g": 20, "b": 0 },
            { "op": "drive_time", "l": -60, "r": -60, "ms": 260 },
            { "op": "if", "cond": { "cmp": [ { "rand": [0, 1] }, "==", 0 ] },
              "body":  [ { "op": "drive_time", "l": -70, "r": 70, "ms": 320 } ],
              "else":  [ { "op": "drive_time", "l": 70, "r": -70, "ms": 320 } ] }
          ],
          "else": [
            { "op": "led", "r": 0, "g": 80, "b": 0 },
            { "op": "drive", "l": 70, "r": 70 }
          ] }
      ] },
    { "event": { "type": "on_button" },
      "body": [ { "op": "stop" }, { "op": "led_off" } ] }
  ]
}
```

## APPENDIX C — Dev shopping list & rover cost sheet

Dev bench (Phase 2 🧍, ~£30): items listed in Phase 2 intro. **Rover end-user cost estimate:** electronics ≈ $22 self-sourced (BOM generator computes live), fasteners ≈ $2, filament ≈ 90 g ≈ $2, cell sourced locally ≈ $5. Printed-for-you option ≈ $12–18 + shipping via network. Keep landing-page claim: *"Build your first real robot for about $35."*

## APPENDIX D — Licensing map

| Scope | License | Why |
|---|---|---|
| `packages/engine`, `apps/*`, platform code | Proprietary (all rights reserved) | The compiler + marketplace is the moat |
| `packages/firmware`, `behavior-ts`, `sim` | GPL-3.0 | Users can hack their robots; forks must share; clones can't close it |
| `robots/`, `registry/`, generated docs/CAD | CC BY-NC-SA 4.0 | Free to build/remix/share; **no commercial resale** |
| Print network fabrication | ToS license grant (Phase 5.9) | Reconciles NC with paid printing on-platform |
| Brand | Registered trademark 🧍 (UK/EU/US) | The real anti-clone lever — file early |

## APPENDIX E — Pricing & unit economics sketch

Pro $4.99/mo · print job example: 90 g rover set → quote ≈ $2.50 + 90×0.07×1.0 = $8.80 + ship ≈ $6 → buyer ≈ $14.80; printer nets ≈ $9.25 after 18% fee ($2.66 to us) with ≈ $2 materials — worthwhile both sides · affiliates 3–8% of ≈ $22 baskets · Month-6 target: 300 Pro subs + 400 print jobs/mo + affiliates ≈ $2.5–3.5k MRR, costs < $300/mo (Vercel/Supabase/API) — solo-sustainable, before kits/PCB margin.

## APPENDIX F — Competitive positioning (context, not tasks)

Otto DIY (open-source biped kits — closest analogue; no generation engine, no sim/builder unification, no print network) · Petoi Bittle (premium quadruped, closed) · SunFounder/ELEGOO (Arduino kit volume, no platform) · LEGO Mindstorms discontinued 2022 (market gap this fills) · M5Stack (modules, not robots). **Differentiators:** manifest compiler (robots are data), one-click sim→robot behavior parity, community print fulfilment, configurator. None of the above have any of these.

## APPENDIX G — Risk register

| Risk | L | I | Mitigation |
|---|---|---|---|
| Print network cold start | H | H | Same-country matching, seed 10 printers pre-launch, Craftcloud link-out fallback on expiry |
| Servo/motor brownouts → support flood | H | M | Slew limits + staggered attach in firmware, boost board with headroom, troubleshooting snippets + AI agent |
| CAD generator complexity balloons | M | H | Support-free design rule, 5-part cap per robot v1, static-STL escape hatch per part if a script fights back |
| Sim/real behavior mismatch erodes trust | M | M | Golden-trace parity tests, conservative physics claims in UI, "sim is a sandbox" copy |
| Blockly scope creep | M | M | Frozen 26-block set (§5.3 rule) |
| AliExpress-style cloning post-traction | M | M | Moat = engine + network + brand ™; NC license deters legit resellers |
| Solo-operator burnout / bus factor | M | H | Sleep-safe automation rule, unattended-overnight test (Phase 5), everything documented in-repo |
| Chargebacks/disputes on prints | M | M | Photo QC gate, buyer approval window, audit trail, small ticket sizes |
| iOS mDNS flakiness | H | L | IP fallback + QR from portal, docs cover it |
| Regulatory misstep (toys/batteries) | L | H | 14+ positioning, no battery shipping, module pre-cert strategy (§H) |

## APPENDIX H — Compliance & safety notes

Age-grade 14+ everywhere (keeps out of EN 71 toy scope) · small-parts & pinch warnings in generated `safety` doc page · no lithium cells sold or shipped, ever — BOM links users to local suppliers · radio compliance via pre-certified ESP32 modules (CE/UKCA/FCC modular approval), EMC self-declaration when kits ship (Phase 8, get test-house quote 🧍) · UK/Gibraltar GDPR: privacy page, Plausible (cookieless), data export/delete via Supabase · distance-selling: digital goods refund policy stated pre-checkout; print jobs are made-to-order (customised goods exemption noted in terms, jurisdiction-dependent — 🧍 legal review) · marketplace: printers act as independent contractors (terms clarify), Stripe Connect handles KYC/payouts.

## APPENDIX I — Effort estimate (focused solo + agent)

| Phase | Weeks |
|---|---|
| 0 Scaffold | 1 |
| 1 Engine + rover | 3–4 |
| 2 Firmware + flash + drive | 3 |
| 3 Builder + sim | 3–4 |
| 4 Platform | 2–3 |
| 5 Print network | 3 |
| 6 Robots 2–3 + configurator | 2 |
| 7 Support agent + launch | 2 |
| **Total to launch** | **≈ 19–22 weeks** |

## APPENDIX J — Kickoff prompts for the agent

- Start: *"Read PLAN.md fully. Execute Phase 0. Follow §0 rules. Stop at every 🧍."*
- Each subsequent session: *"Read PLAN.md §0 and docs/reports/. Continue from the first unmet acceptance item."*
- New robot later: *"Author robots/<id>/ per §5.2 using only data files; run botforge build; if code changes seem needed, stop and propose a DECISIONS entry."*

*End of plan v1.0 — changes to this document require a DECISIONS.md entry.*

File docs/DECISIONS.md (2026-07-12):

# DECISIONS.md

Running log of decisions and deviations from PLAN.md, per §0 rule 2.
Format: date · decision · reason.

---

## 2026-07-12 — Local Python 3.11, CI/Docker Python 3.12

PLAN §4.2 fixes Python 3.12. The development sandbox cannot download a 3.12
interpreter (proxy blocks the python-build-standalone GitHub release assets),
so `packages/engine` declares `requires-python = ">=3.11"` and is developed
against 3.11 locally. CI (`setup-uv`/`setup-python`) and the engine Docker
image (`python:3.12-slim-bookworm`) both use 3.12, which remains the canonical
runtime. No 3.12-only syntax is used.

## 2026-07-12 — pnpm 10 instead of pnpm 9

PLAN §4.2 says pnpm 9. The environment ships pnpm 10.33 (a strict superset for
our purposes); pinning back to 9 would require corepack downloads that the
proxy may block. `packageManager` is pinned to `pnpm@10.33.0`. No pnpm-9-only
behavior is relied on.

## 2026-07-12 — pioarduino platform fork for arduino-esp32 core 3.x

PLAN §4.2 requires arduino-esp32 core 3.x on ESP32-S3. The official PlatformIO
`espressif32` platform stopped at core 2.x; the community-maintained
`pioarduino/platform-espressif32` fork is the standard way to get core 3.x
under PlatformIO. `packages/firmware/platformio.ini` pins a released zip of
that fork.

## 2026-07-12 — PrusaSlicer from Debian repo (2.5.x) in the engine image

PLAN §4.2/Phase 0.4 say "PrusaSlicer CLI (AppImage extracted)". Upstream
AppImage asset names embed build timestamps (not stably pinnable) and need
FUSE workarounds in containers. Debian bookworm ships `prusa-slicer` 2.5.x
whose CLI emits the same `; filament used [g]` / estimated-time gcode comments
the print-plan generator parses. The engine image installs it via apt. If a
2.7+ feature is ever needed, revisit with a pinned AppImage mirror.

## 2026-07-12 — §5.1 pin-type enum extended with `motor_out` and `switch`

PLAN §5.1 fixes pin types to `gpio, pwm, adc, i2c_sda, i2c_scl, 5v, 3v3, gnd,
vbat`, but the frozen §5.2 rover manifest wires endpoints that none of those
types can describe: `mdrv.aout1..bout2 → motor_left/right.m1/m2` (H-bridge
outputs to motor terminals) and `sw.a/b → pwr.out_switch_a/b` (mechanical
switch inline on the boost rail). Two types are added: `motor_out` (driver
output / motor terminal, legal only against another `motor_out`) and `switch`
(switch terminal / switched-rail terminal, legal only against another
`switch`). Migration note: no existing data predates this — the enum ships
extended from the first registry commit. This is the minimal change that
makes the frozen rover manifest validate.

## 2026-07-12 — Core GPIO capability map lives in `firmware.params`

§5.1's launch-module table says the core module "exposes gpio map" without
specifying where. Rather than extend the frozen module schema, the core
module's free-form `firmware.params` dict carries `available_gpios`,
`adc1_gpios`, and `reserved_gpios`. The validator (required pins, ADC-only
rule, double-booking, reserved pins) and the firmware-config generator read it
from there. Core `pins:` lists only the power pins (5v/3v3/gnd); `gpioN`
endpoint names are validated against `available_gpios`.

## 2026-07-12 — CadQuery ≥2.4 resolves to 2.8.x

PLAN §4.2 names CadQuery 2.4; the current release line (2.8.x, same API for
everything cadlib uses) installs cleanly on Python 3.11/3.12 with prebuilt OCP
wheels. The engine declares `cadquery>=2.4` in the optional `cad` extra and CI
uses the resolved 2.8.x. No 2.4-only pinning reason exists.

## 2026-07-12 — §5.5 config.json: real pin names and manifest ordering

The frozen §5.5 example shows `line` pins as `"l"/"r"` and lists `pwr` last.
The registry defines the line-sensor pins as `out_l`/`out_r`, and §5.5's own
rule ("derived entirely from robot.yaml connections") means pin keys come from
the registry pin names — the example's `l`/`r` shorthand loses information, so
the real names win. Module order follows manifest order (deterministic,
derivable), which places `pwr` first rather than last. Everything else in the
example is reproduced byte-exactly and frozen in a test.

## 2026-07-12 — Golden tests: full text for text artifacts, existence/QC for binaries

Phase 1.15 asks for "hashes for binary files". STEP files embed export
timestamps, PNG bytes depend on the GL rasterizer build, and SVG layout varies
across graphviz releases — hashing any of them would make goldens fail on
byte-noise, not regressions. Instead: every TEXT artifact (json/yaml/csv/
md/mdx/urdf) is committed in full for `_test-min` and hash-snapshotted for
`rover-v1`; binaries are checked for presence + non-zero size, with geometry
regressions caught by the (text) `cad/qc_report.json` volumes/bboxes and the
URDF masses. Print estimates in goldens use a committed deterministic fake
slicer; the real-slicer 60–180 g sanity check runs where PrusaSlicer exists
(the CI engine container).

## 2026-07-12 — companion-v1 added to the roadmap (owner request)

Lewis requested a more complex flagship robot: rolls, follows its user, has AI
chat, user-customisable abilities. Choices made: rolling form factor (not
biped), app-first chat with onboard voice as a configurator upgrade, camera
person-tracking for follow-me. Spec: docs/proposals/COMPANION-V1.md. It slots
into Phase 6 as robot #3 (arm-v1 → BACKLOG) with the AI-chat platform work in
Phase 7. Phase order and §5 contracts unchanged; new capability arrives as
registry modules + firmware drivers, per the plan's own extension rules.

## 2026-07-12 — ESLint: flat v9 at root, legacy v8 inside apps/web

`next lint` on Next.js 14 requires eslint 8 + eslint-config-next. Rest of the
workspace uses the root prettier + per-package `tsc --noEmit` for linting in
Phase 0. Revisit if/when the web app moves to Next 15.
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

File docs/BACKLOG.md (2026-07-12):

# BACKLOG.md

Good ideas that are out of scope for the current phase (§0 rule 11).
Do not implement anything here without promoting it into a phase.

- arm-v1 desktop arm (displaced from Phase 6 by companion-v1 — see
  docs/proposals/COMPANION-V1.md; still a good robot #4)
- led-ws2812-8 ring module (companion face upgrade)
- `on_person` BSJ event (only if on_tick polling of person.* proves clumsy — §5.3 freeze)

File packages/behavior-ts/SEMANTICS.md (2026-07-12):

# BSJ v1 — Execution Semantics (normative)

This document pins down every deterministic detail of the Behavior Script JSON
(BSJ) v1 interpreter, beyond what PLAN.md §5.3 specifies. **Both** interpreters
— the TypeScript reference (`packages/behavior-ts/src/interpreter.ts`) and the
C++ firmware VM (`packages/firmware/src/vm/`) — implement exactly this, and the
shared golden-trace fixtures (`packages/behavior-ts/fixtures/`) prove it.

## 1. Numbers

- All expression values are IEEE-754 **binary32** (C++ `float`). The TS
  interpreter applies `Math.fround` after every arithmetic operation, sensor
  read, `call`, and variable store, so both implementations compute identical
  bit patterns.
- **Truthiness**: a value is truthy iff it is `!= 0.0`. `cmp`, `logic`, and
  `not` produce exactly `1.0` or `0.0`.
- **Rounding to int** (at the HAL boundary and for `ms` / `repeat n` / `rand`
  bounds): `roundInt(x) = floor(x + 0.5)`, computed in float32
  (C++ `(long)floorf(x + 0.5f)`, TS `Math.floor(fround(fround(x) + 0.5))`).
- **Clamping** after rounding: `drive` / `drive_time` l,r → [-100, 100];
  `led` r,g,b → [0, 255]; `servo` / `servo_sweep` deg → [0, 180]. Other int
  params (`tone` hz/ms, led `id`) are rounded but not clamped. `wait` /
  `drive_time` / `servo_sweep` `ms` values < 0 are treated as 0.
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

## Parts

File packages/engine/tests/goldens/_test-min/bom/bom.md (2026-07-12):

# Bill of materials — Test Min

## Electronics

| Ref | Part | Qty | Unit (USD) | Total (USD) | Buy |
| --- | --- | ---: | ---: | ---: | --- |
| `core-esp32s3-devkit` | ESP32-S3-DevKitC-1 dev board (N8R2) | 1 | 8.00 | 8.00 | [aliexpress](https://botforge.example/out/ali/core-esp32s3-devkit) · [amazon](https://botforge.example/out/amz/core-esp32s3-devkit) |
| `led-ws2812-2` | 2-pixel WS2812 LED eyes | 1 | 0.50 | 0.50 | [aliexpress](https://botforge.example/out/ali/led-ws2812-2) · [amazon](https://botforge.example/out/amz/led-ws2812-2) |
| `buzzer-passive` | Passive piezo buzzer | 1 | 0.30 | 0.30 | [aliexpress](https://botforge.example/out/ali/buzzer-passive) · [amazon](https://botforge.example/out/amz/buzzer-passive) |

## Fasteners

| Ref | Part | Qty | Unit (USD) | Total (USD) | Buy |
| --- | --- | ---: | ---: | ---: | --- |
| `m2x6_selftap` | M2×6 self-tapping screw | 2 | 0.02 | 0.04 | [aliexpress](https://botforge.example/out/ali/m2x6_selftap) |

## Printed parts

| Part | Qty | Material | Color role | Grams |
| --- | ---: | --- | --- | ---: |
| `plate` | 1 | PLA | body | — |

## Totals

| | |
| --- | ---: |
| Electronics | $8.80 |
| Fasteners | $0.04 |
| Filament | — |
| **Estimated total** (filament excluded) | **$8.84** |

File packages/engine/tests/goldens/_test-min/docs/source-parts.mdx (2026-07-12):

---
title: "Source the parts"
description: "Every part Test Min needs, with quantities, prices and buy links."
sidebar:
  order: 3
---

Everything Test Min needs, in three shopping lists: electronic modules,
fasteners, and the parts you print yourself. Prices are estimates — modules
like these are commodity parts, so feel free to shop around.

## Electronics

| Module | Qty | Price (USD, est.) | Where to buy |
| --- | --- | --- | --- |
| ESP32-S3-DevKitC-1 dev board (N8R2) | 1 | 8.00 | [BUY](https://botforge.example/out/ali/core-esp32s3-devkit) |
| 2-pixel WS2812 LED eyes | 1 | 0.50 | [BUY](https://botforge.example/out/ali/led-ws2812-2) |
| Passive piezo buzzer | 1 | 0.30 | [BUY](https://botforge.example/out/ali/buzzer-passive) |

## Fasteners

| Fastener | Spec | Qty |
| --- | --- | --- |
| M2×6 self-tapping screw | M2 x 6 mm pan head, self-tapping, for printed plastic | 2 |

Fasteners are cheapest in assortment packs — one pack covers many robots.

## Printed parts

The plastic parts are not bought — you print them (or have a print service or
community member print them for you). See the [print guide](./print-guide/)
for the full list of parts, materials and print settings.

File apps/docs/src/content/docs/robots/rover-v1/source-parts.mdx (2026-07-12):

---
title: "Source the parts"
description: "Every part Rover needs, with quantities, prices and buy links."
sidebar:
  order: 3
---

Everything Rover needs, in three shopping lists: electronic modules,
fasteners, and the parts you print yourself. Prices are estimates — modules
like these are commodity parts, so feel free to shop around.

## Electronics

| Module | Qty | Price (USD, est.) | Where to buy |
| --- | --- | --- | --- |
| ESP32-S3-DevKitC-1 dev board (N8R2) | 1 | 8.00 | [BUY](https://botforge.example/out/ali/core-esp32s3-devkit) |
| 1S Li-ion power board (charger + 5V boost) | 1 | 2.50 | [BUY](https://botforge.example/out/ali/pwr-1s-boost) |
| DRV8833 dual motor driver | 1 | 1.50 | [BUY](https://botforge.example/out/ali/drv-8833) |
| N20 metal-gear motor (6V 150RPM) | 2 | 3.00 | [BUY](https://botforge.example/out/ali/motor-n20) |
| VL53L0X time-of-flight distance sensor | 1 | 2.50 | [BUY](https://botforge.example/out/ali/sens-vl53l0x) |
| 2-channel TCRT5000 line sensor | 1 | 1.50 | [BUY](https://botforge.example/out/ali/sens-line-2ch) |
| 2-pixel WS2812 LED eyes | 1 | 0.50 | [BUY](https://botforge.example/out/ali/led-ws2812-2) |
| Passive piezo buzzer | 1 | 0.30 | [BUY](https://botforge.example/out/ali/buzzer-passive) |
| SPDT slide switch | 1 | 0.20 | [BUY](https://botforge.example/out/ali/sw-slide) |

## Fasteners

| Fastener | Spec | Qty |
| --- | --- | --- |
| M2×6 self-tapping screw | M2 x 6 mm pan head, self-tapping, for printed plastic | 8 |
| M2×8 self-tapping screw | M2 x 8 mm pan head, self-tapping, for printed plastic | 4 |
| 6 mm steel ball for caster | 6 mm chrome steel bearing ball (G25) | 1 |

Fasteners are cheapest in assortment packs — one pack covers many robots.

## Printed parts

The plastic parts are not bought — you print them (or have a print service or
community member print them for you). See the [print guide](./print-guide/)
for the full list of parts, materials and print settings.

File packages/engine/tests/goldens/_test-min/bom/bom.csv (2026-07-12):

section | ref | name | qty | unit_price_usd | line_total_usd | vendor | url
electronics | core-esp32s3-devkit | ESP32-S3-DevKitC-1 dev board (N8R2) | 1 | 8.00 | 8.00 | aliexpress | https://botforge.example/out/ali/core-esp32s3-devkit
electronics | led-ws2812-2 | 2-pixel WS2812 LED eyes | 1 | 0.50 | 0.50 | aliexpress | https://botforge.example/out/ali/led-ws2812-2
electronics | buzzer-passive | Passive piezo buzzer | 1 | 0.30 | 0.30 | aliexpress | https://botforge.example/out/ali/buzzer-passive
fasteners | m2x6_selftap | M2×6 self-tapping screw | 2 | 0.02 | 0.04 | aliexpress | https://botforge.example/out/ali/m2x6_selftap
printed | plate | plate | 1

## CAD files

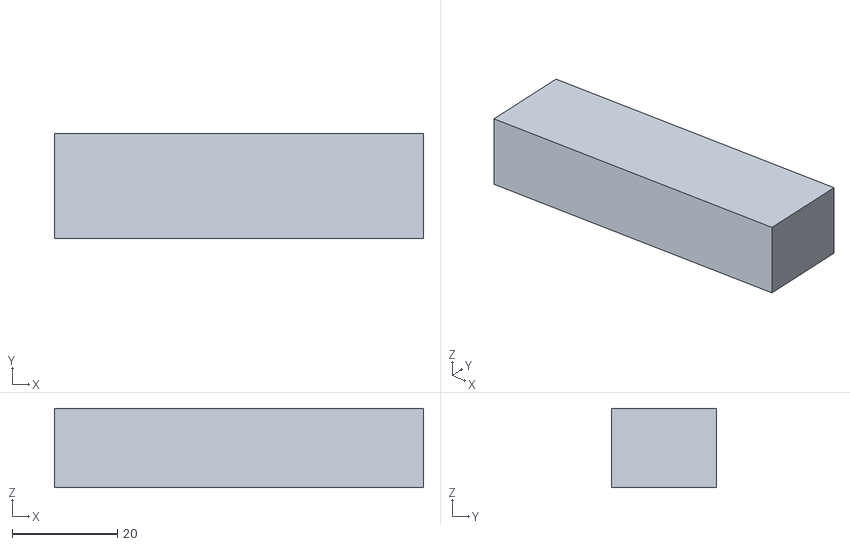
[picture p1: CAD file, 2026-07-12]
apps/web/public/sim-assets/rover-v1/meshes/pwr.stl
70.0 x 20.0 x 15.0

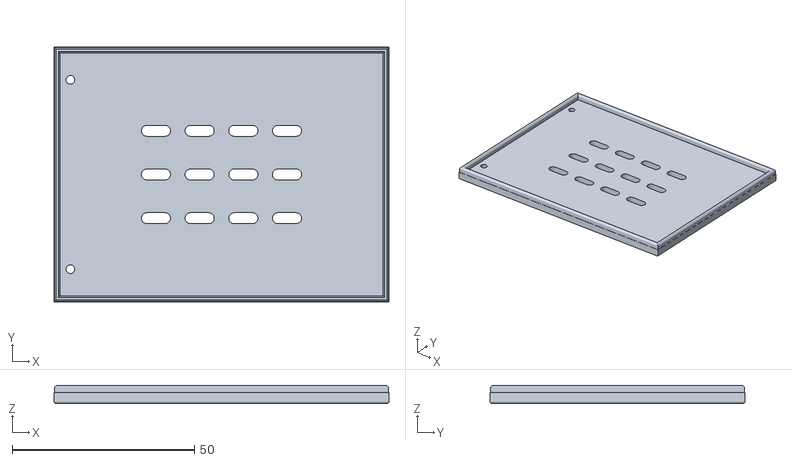
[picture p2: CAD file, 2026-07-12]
apps/web/public/sim-assets/rover-v1/meshes/lid.stl
92.0 x 70.0 x 5.00

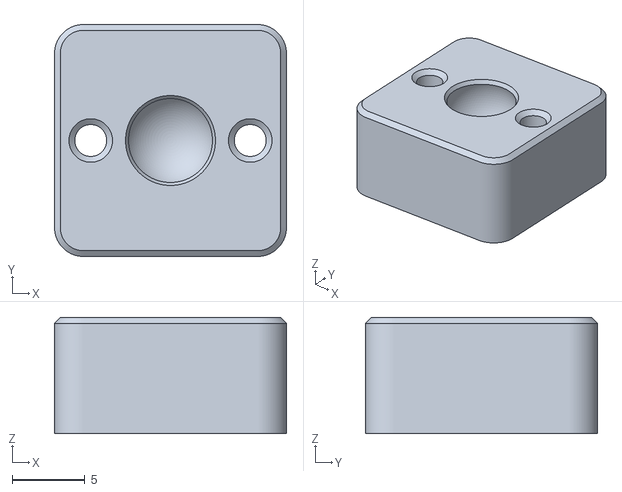
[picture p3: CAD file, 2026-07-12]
apps/web/public/sim-assets/rover-v1/meshes/caster_mount.stl
16.0 x 16.0 x 8.00

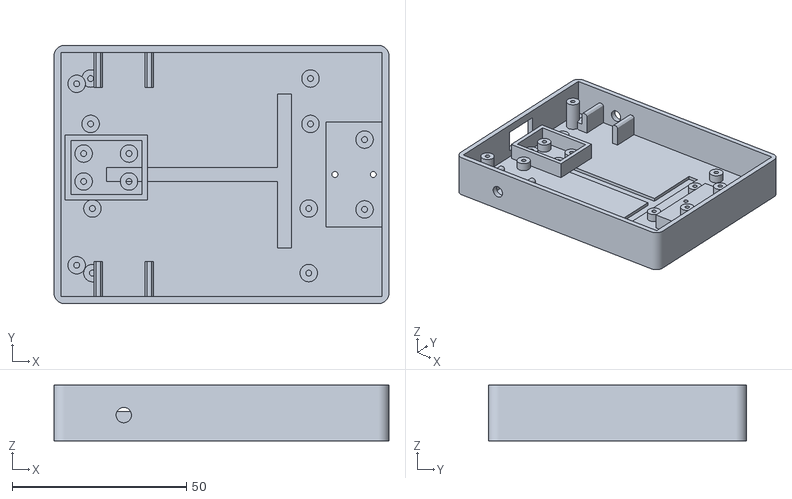
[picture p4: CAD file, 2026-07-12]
apps/web/public/sim-assets/rover-v1/meshes/chassis.stl
96.0 x 74.0 x 16.0

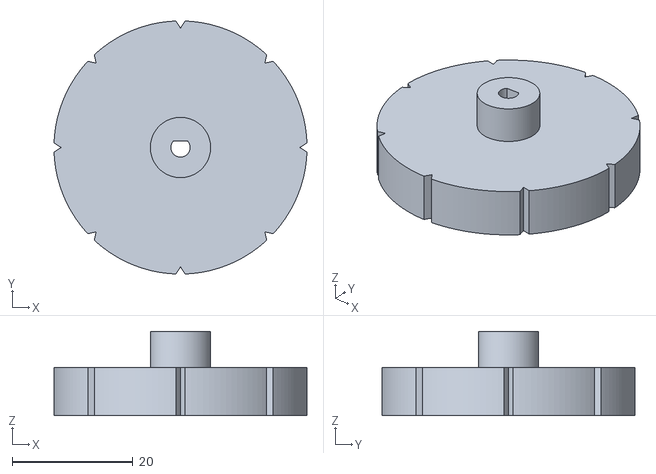
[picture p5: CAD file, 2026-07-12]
apps/web/public/sim-assets/rover-v1/meshes/wheel_2.stl
42.0 x 42.0 x 14.0

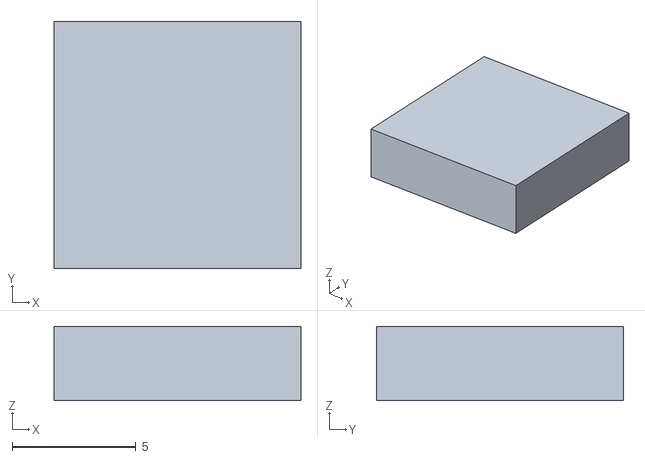
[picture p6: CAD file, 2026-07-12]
apps/web/public/sim-assets/rover-v1/meshes/eyes.stl
10.0 x 10.0 x 3.00

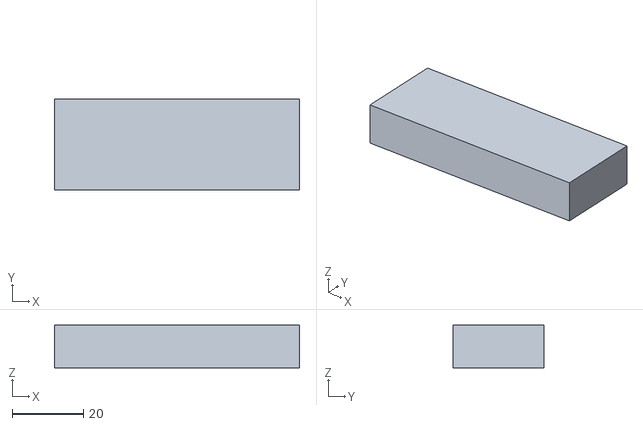
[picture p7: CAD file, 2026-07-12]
apps/web/public/sim-assets/rover-v1/meshes/core.stl
69.0 x 25.5 x 12.0

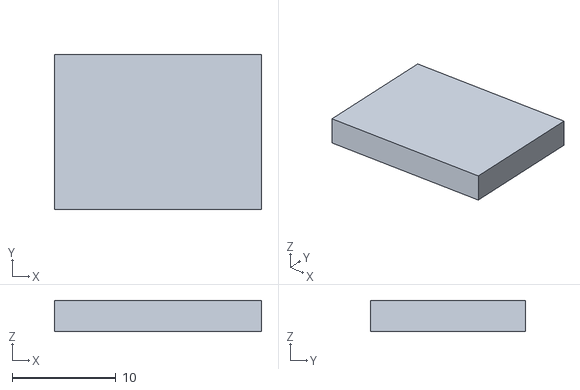
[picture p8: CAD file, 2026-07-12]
apps/web/public/sim-assets/rover-v1/meshes/mdrv.stl
20.0 x 15.0 x 3.00

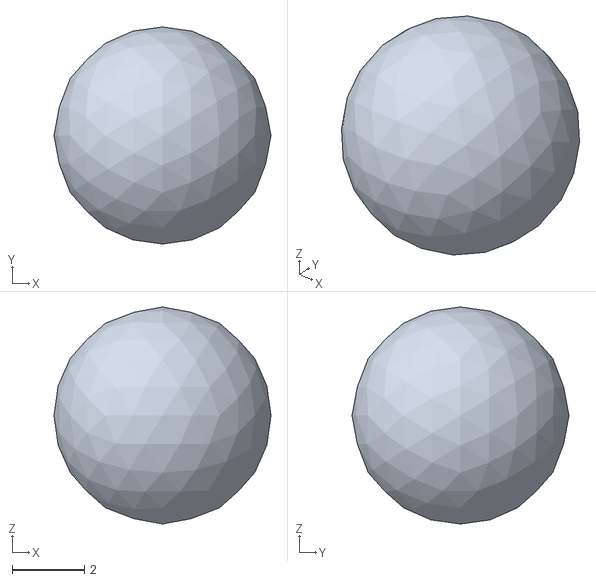
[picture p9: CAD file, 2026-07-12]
apps/web/public/sim-assets/rover-v1/meshes/m3_ball_6mm.stl
6.00 x 6.00 x 6.00

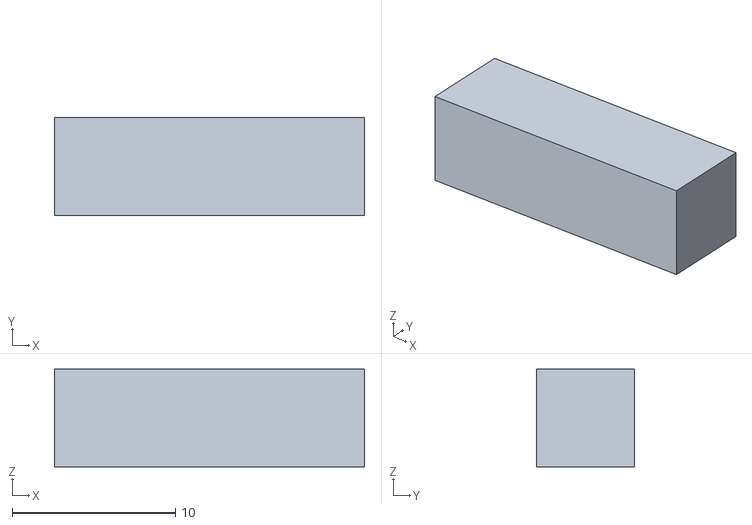
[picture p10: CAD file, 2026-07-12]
apps/web/public/sim-assets/rover-v1/meshes/sw.stl
19.0 x 6.00 x 6.00

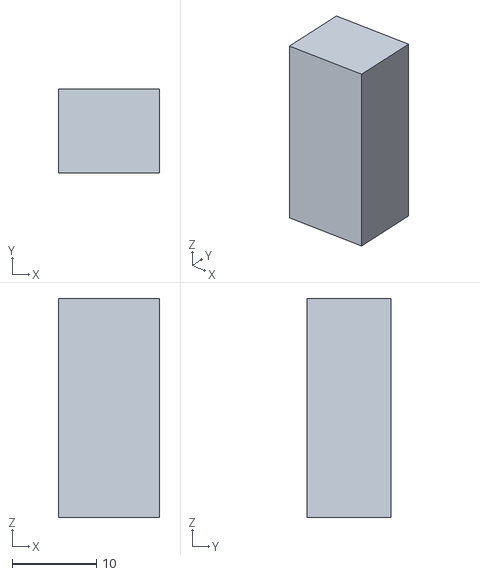
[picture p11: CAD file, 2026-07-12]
apps/web/public/sim-assets/rover-v1/meshes/motor_left.stl
12.0 x 10.0 x 26.0

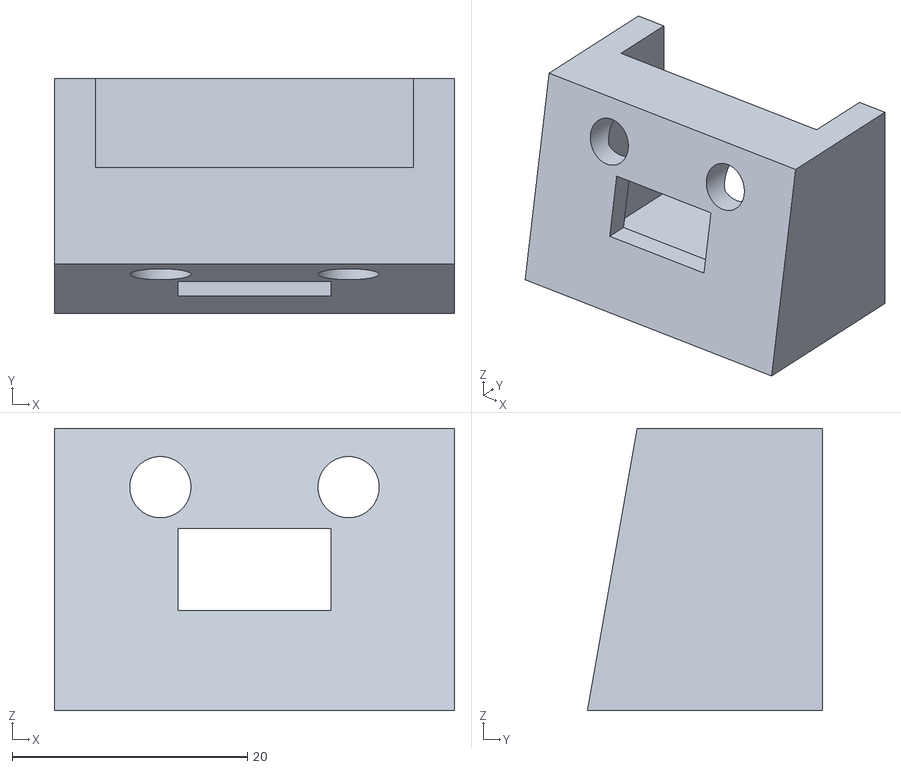
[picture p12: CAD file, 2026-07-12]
apps/web/public/sim-assets/rover-v1/meshes/head.stl
34.0 x 20.0 x 24.0

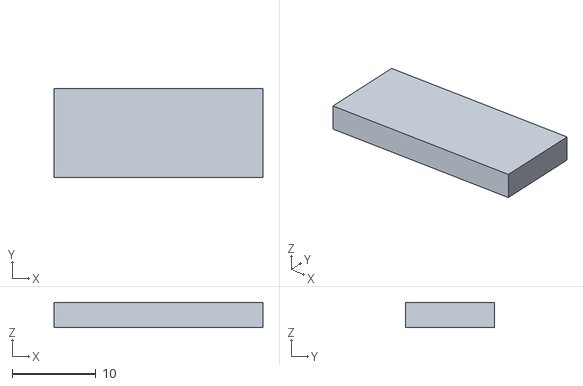
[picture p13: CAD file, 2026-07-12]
apps/web/public/sim-assets/rover-v1/meshes/range.stl
25.0 x 10.7 x 3.00

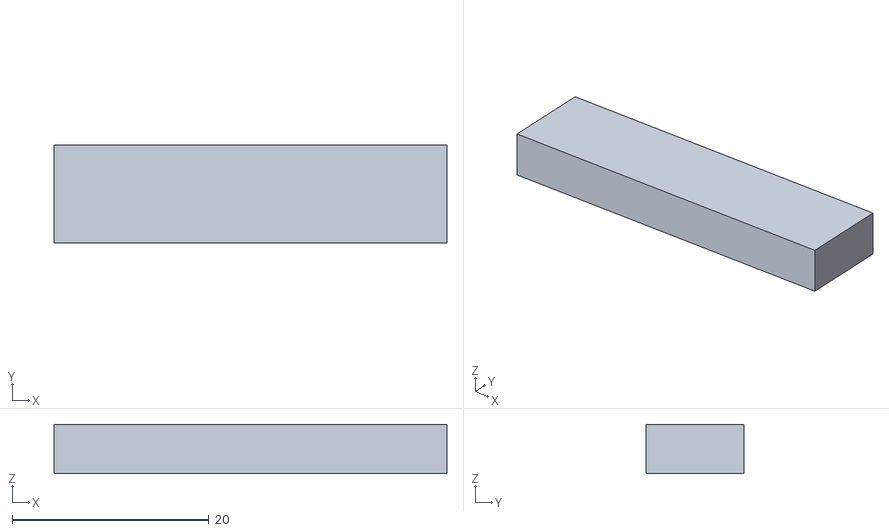
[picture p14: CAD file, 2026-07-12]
apps/web/public/sim-assets/rover-v1/meshes/line.stl
40.0 x 10.0 x 5.00

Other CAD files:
apps/web/public/sim-assets/rover-v1/meshes/buzz.stl

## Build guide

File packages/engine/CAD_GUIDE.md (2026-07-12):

# CAD_GUIDE — conventions for BOTFORGE printed parts

Every printed part in `robots/<id>/parts/*.py` and every helper in
`botforge_engine/cadlib/` follows these rules. The `cad` generator enforces
the QC rules on every build.

## Units, axes, origin

- **Units: millimetres.** Everywhere — scripts, params, QC report.
- **Z-up.** `z = 0` is the print bed; parts are modelled in their print
  orientation, never rotated for printing afterwards.
- **Origin at the part's center bottom**: XY-centered footprint, solid rising
  from `z = 0`. If the part is used in another orientation (e.g. the lid or
  the caster mount are flipped in the assembly), that flip happens in the
  assembly poses — the script still models print-orientation, bed at `z = 0`.

## The script contract

```python
def build(params: dict) -> cq.Workplane: ...
```

- One part per script, exposing exactly this function. `params` comes from
  the manifest's `printed_parts[].params`; scripts keep a module-level
  `DEFAULTS` dict and merge (`params` wins) so a bare `build({})` works.
- Return a single `cq.Workplane` carrying the finished solid. No file I/O, no
  globals mutated, deterministic output for the same params.
- Scripts may import `botforge_engine.cadlib` (they run inside the engine
  process). Keep scripts short (< ~120 lines) and params-driven.

## Fits and walls — `cadlib` constants

- `FIT = 0.20` — clearance added to every press/slide fit. A bore for a 3 mm
  shaft is Ø3.2; a lip for a 92 mm opening is 91.8. Use `FIT` (or `FIT/2` per
  side) instead of inventing clearances.
- `WALL_MIN = 1.6` — minimum wall/feature thickness (about four 0.4 mm
  perimeters). Nothing structural thinner than this.

## Support-free printing (hard rule)

All parts print support-free, flat on the bed:

- **Overhangs ≤ 45°** from vertical. Model downward-facing transitions as 45°
  ramps/gables, not horizontal ceilings.
- **Chamfer, don't fillet, downward-facing features.** A fillet under an
  overhang starts tangent-horizontal and will droop; a ≤45° chamfer prints
  clean. Fillets are fine on vertical edges (`edges("|Z")`) and top edges.
- Small horizontal holes (≤ ~6 mm, e.g. shaft and eye holes) and short wall
  cutouts are allowed — printers bridge them — but they are counted by the
  overhang report, so keep them rare and small.
- Interior cavities need sloped (≤45°... i.e. ≥45° from horizontal) ceilings
  or must open upward/rearward (see `head.py`'s 45° pocket roof).

## QC rules (enforced by the `cad` generator)

Each exported STL is checked with trimesh (loaded with `validate=True`,
which drops zero-area degenerate triangles — an OCC tessellation artifact at
sphere poles — and welds duplicate vertices, exactly as slicers do):

- **Watertight** — hard error if not.
- **Volume > 0** — hard error if not.
- **Bounding box ≤ 200 × 200 × 200 mm** — hard error if not.
- **Overhang report**: % of face area with normal `z < -cos(40°)` (faces
  steeper than 50° facing down), excluding triangles entirely below
  `z = 0.5 mm` (bed contact). More than **2%** ⇒ build warning
  `part <id>: N.N% support-needing overhangs`. Target 0%.

Results are written to `dist/<id>/cad/qc_report.json` as
`{part_id: {watertight, volume_mm3, bbox, overhang_pct}}`, floats rounded to
2 dp, no timestamps or absolute paths (deterministic).

## Exports

Per part id (qty is handled downstream): `cad/stl/<id>.stl` (linear
deflection tolerance 0.05 mm), `cad/step/<id>.step`, `cad/3mf/<id>.3mf`
(CadQuery exports 3MF natively).

## cadlib helpers

| Helper | Kind | Notes |
| --- | --- | --- |
| `plate(l, w, t, corner_r=3)` | base | rounded-corner plate, z 0..t |
| `boss_m2_selftap(h)` | union  | Ø5 boss, Ø1.7 self-tap pilot through |
| `pocket_sg90(depth=16)` | cutter | 23.2×12.6 body + flush tab slots + pilots |
| `clamp_n20()` | union  | friction walls for the 12×10 N20 body, 10 mm long |
| `pocket_pcb(dims, standoff)` | union  | perimeter wall + 4 corner standoffs (never cut a pocket into a thin floor) |
| `wire_channel(l, path_w=4, depth=3)` | cutter | straight open channel bar |
| `snapless_lip(l, w, h=2)` | union  | lid lip ring, outer = opening − FIT, chamfered lead-in |

_Positive features_ sit on `z = 0` and are unioned onto a body; _cutters_ are
translated into place and cut. All helpers are XY-centered on their own
origin.

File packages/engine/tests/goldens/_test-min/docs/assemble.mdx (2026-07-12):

---
title: "Assemble"
description: "Step-by-step assembly guide for Test Min."
sidebar:
  order: 6
---

Build Test Min one step at a time, LEGO style. New parts in each
picture are shown in color; parts you already placed are ghosted grey.

## Step 1 — Mount the brain

Step 1: Mount the brain

Fasteners for this step:

- M2×6 self-tapping screw x2 — M2 x 6 mm pan head, self-tapping, for printed plastic

## Step 2 — Eyes and beeper

Step 2: Eyes and beeper

Press-fit both boards.

That's the hardware done. Next stop: [flash the firmware](./flash/).

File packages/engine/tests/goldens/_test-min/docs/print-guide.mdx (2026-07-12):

---
title: "Print the parts"
description: "Print settings and filament/time estimates for Test Min\u0027s printed parts."
sidebar:
  order: 4
---

All of Test Min's printed parts are designed to print **without
supports**: no overhang tricks, no rafts, no glue. Any well-tuned FDM printer
with a 0.4 mm nozzle can produce them.

## Settings

Use the `pla-0.20` profile that ships with this robot, or dial in the same
values by hand:

- **Layer height:** 0.2 mm
- **Walls / perimeters:** 3
- **Infill:** 15% gyroid
- **Supports:** none — every part is support-free by design
- Print each part flat on the bed in its default orientation.

## Parts

| Part | Qty | Material | Color role | Filament (per part) | Time (per part) |
| --- | --- | --- | --- | --- | --- |
| `plate` | 1 | PLA | body | 12.50 g | 66 min |

The **color role** column tells you which filament color each part uses: keep
all `body` parts one color and all `accent` parts another, and the robot will
look the way it does on the site — but this is your build, so any palette goes.

## Totals

- Filament: about **12.50 g** across all parts.
- Print time: about **66 minutes** of printing.

When everything is off the bed, check each part against the photos in the
[assembly guide](./assemble/), then move on to [wiring](./wiring/).

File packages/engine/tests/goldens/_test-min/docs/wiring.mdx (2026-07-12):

---
title: "Wire it up"
description: "The wiring diagram and wire list for Test Min."
sidebar:
  order: 5
---

Every connection in Test Min uses simple push-on jumper wires — no
soldering iron required. Wire colors in the diagram match the colors in the
wire list, so you can check your work at a glance.

## Wiring diagram

Wiring diagram for Test Min

## Wire list

| From | To | Color | Length (mm) |
| --- | --- | --- | --- |
| `core.gpio38` | `eyes.din` | GN | 40 |
| `core.5v` | `eyes.vcc` | RD | 40 |
| `core.gnd` | `eyes.gnd` | BK | 40 |
| `core.gpio16` | `buzz.sig` | YE | 30 |
| `core.gnd` | `buzz.gnd` | BK | 30 |

Cut or buy jumper wires a little longer than listed — slack is easier to tuck
away than a wire that is 5 mm too short. When everything matches the diagram,
continue to [assembly](./assemble/).

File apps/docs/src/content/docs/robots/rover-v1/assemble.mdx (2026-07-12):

---
title: "Assemble"
description: "Step-by-step assembly guide for Rover."
sidebar:
  order: 6
---

Build Rover one step at a time, LEGO style. New parts in each
picture are shown in color; parts you already placed are ghosted grey.

## Step 1 — Print check

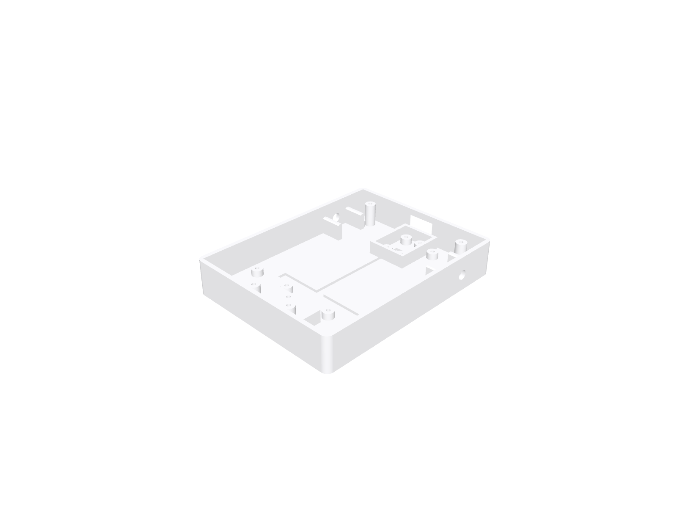
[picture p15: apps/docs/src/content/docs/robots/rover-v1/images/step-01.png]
Step 1: Print check


Confirm all printed parts against the print guide.

## Step 2 — Fit the left motor

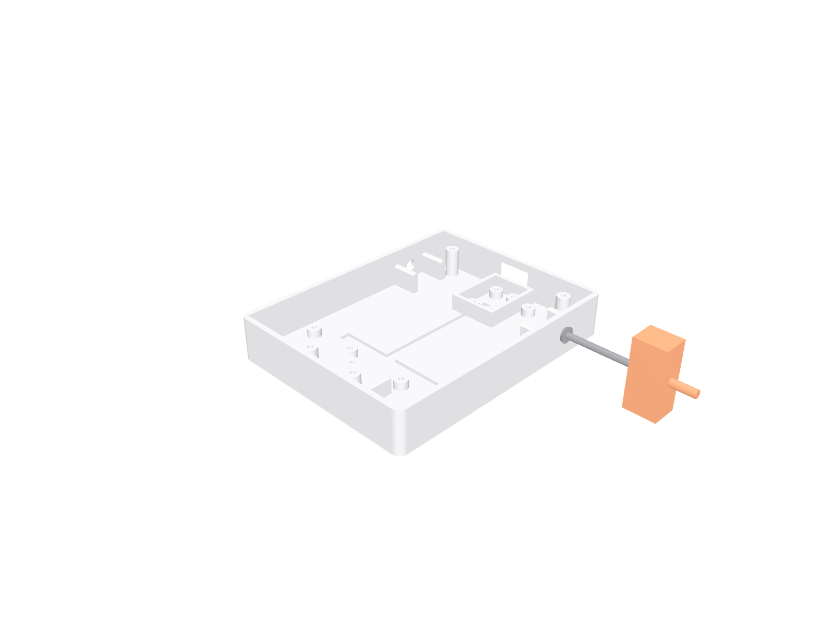
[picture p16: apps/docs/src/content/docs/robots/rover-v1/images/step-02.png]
Step 2: Fit the left motor


Wires face inward.

Fasteners for this step:

- M2×8 self-tapping screw x2 — M2 x 8 mm pan head, self-tapping, for printed plastic

## Step 3 — Fit the right motor

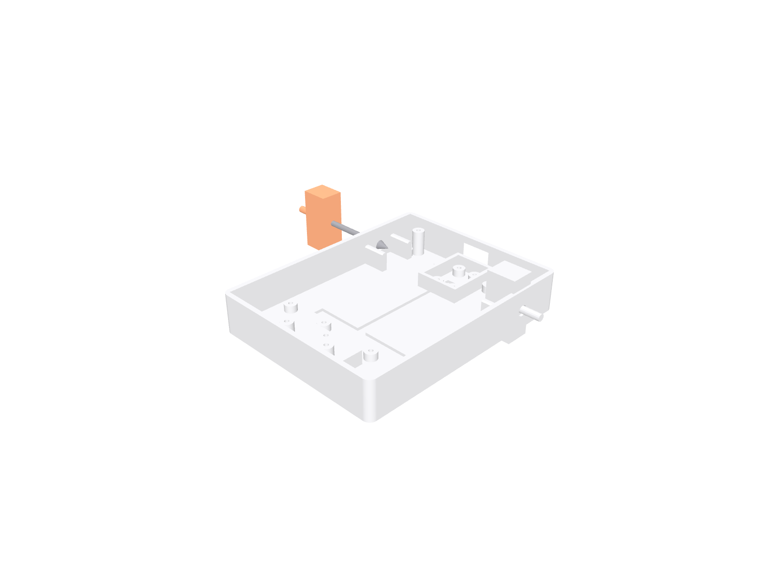
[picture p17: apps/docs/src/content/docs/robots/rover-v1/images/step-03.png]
Step 3: Fit the right motor


Mirror of step 2.

Fasteners for this step:

- M2×8 self-tapping screw x2 — M2 x 8 mm pan head, self-tapping, for printed plastic

## Step 4 — Caster ball

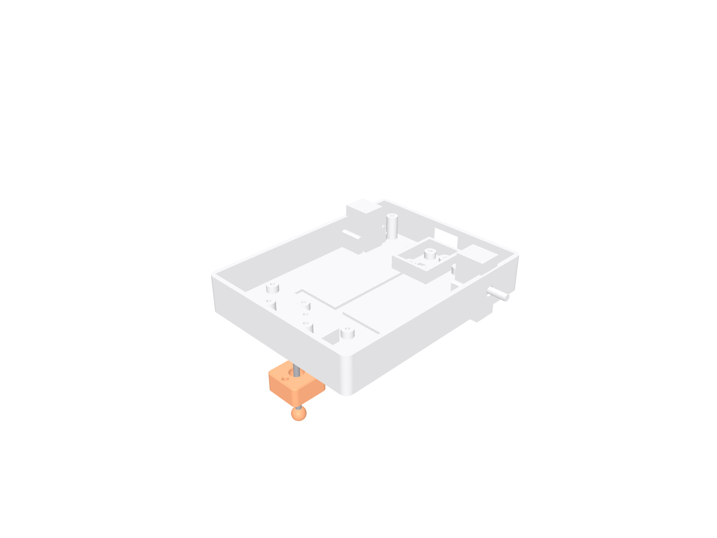
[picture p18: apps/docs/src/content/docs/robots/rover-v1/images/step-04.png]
Step 4: Caster ball


Fasteners for this step:

- M2×6 self-tapping screw x2 — M2 x 6 mm pan head, self-tapping, for printed plastic

## Step 5 — Motor driver

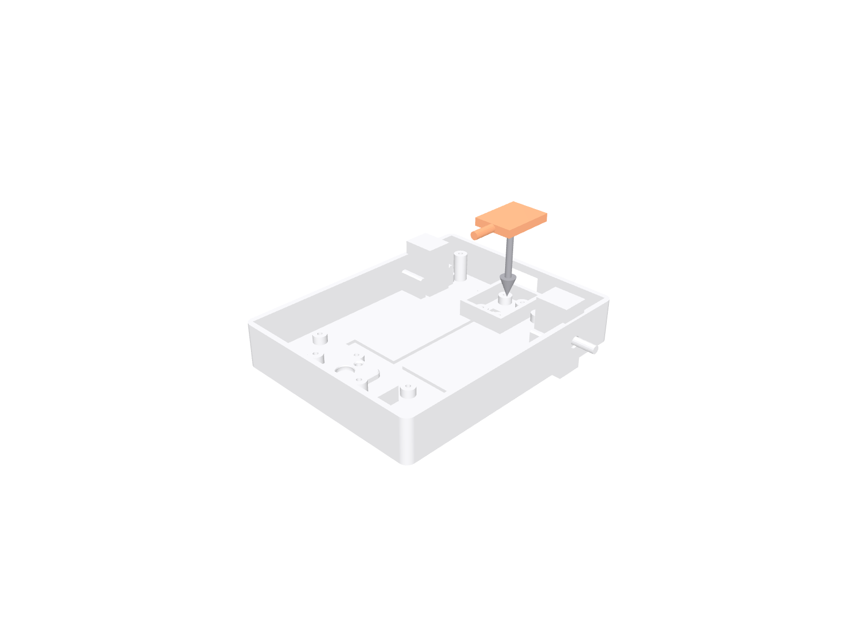
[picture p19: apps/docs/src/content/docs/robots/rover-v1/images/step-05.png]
Step 5: Motor driver


Fasteners for this step:

- M2×6 self-tapping screw x2 — M2 x 6 mm pan head, self-tapping, for printed plastic

## Step 6 — Power board + switch

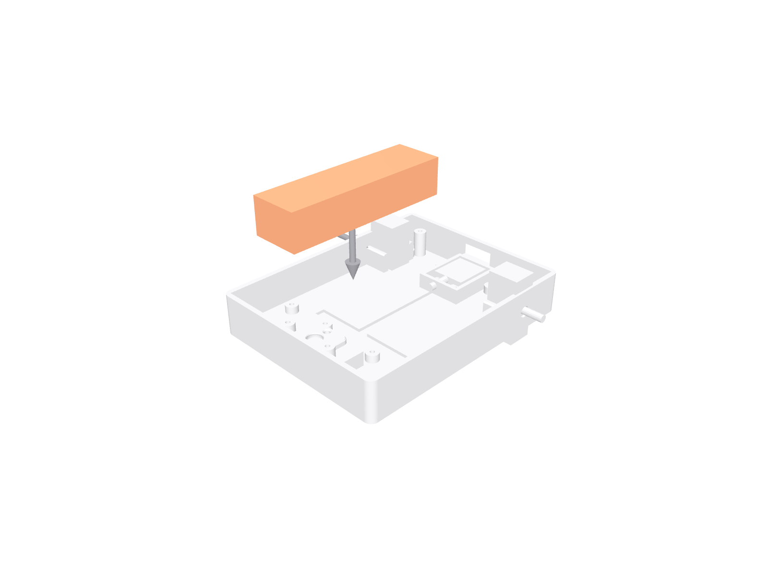
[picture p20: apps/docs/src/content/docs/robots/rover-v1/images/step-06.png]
Step 6: Power board + switch


## Step 7 — The brain

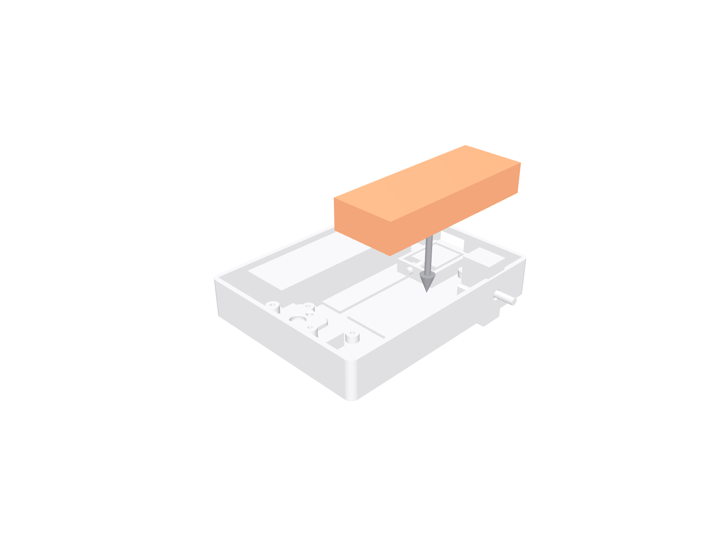
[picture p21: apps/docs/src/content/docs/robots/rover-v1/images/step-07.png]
Step 7: The brain


USB port faces the rear cutout.

## Step 8 — Wire it up

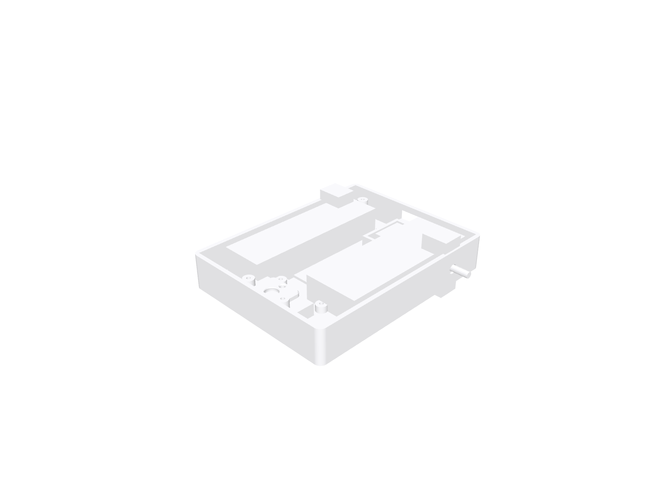
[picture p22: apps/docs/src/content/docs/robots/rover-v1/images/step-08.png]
Step 8: Wire it up


Follow the wiring diagram page — colors match.

## Step 9 — Sensors into the head

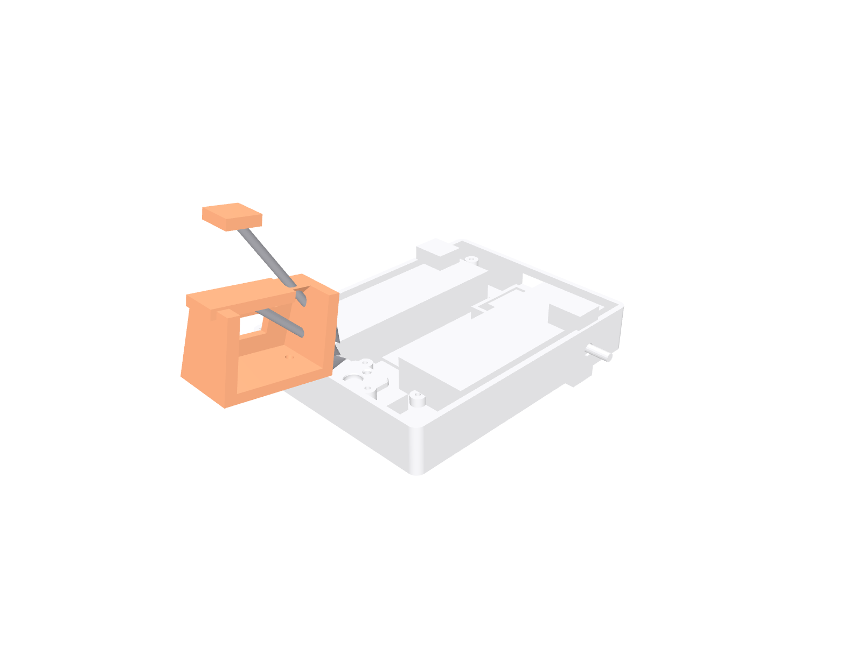
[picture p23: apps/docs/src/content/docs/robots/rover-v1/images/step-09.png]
Step 9: Sensors into the head


Press the distance sensor into the pocket behind the face (window at the front)

Fasteners for this step:

- M2×6 self-tapping screw x2 — M2 x 6 mm pan head, self-tapping, for printed plastic

## Step 10 — Line sensors + beeper

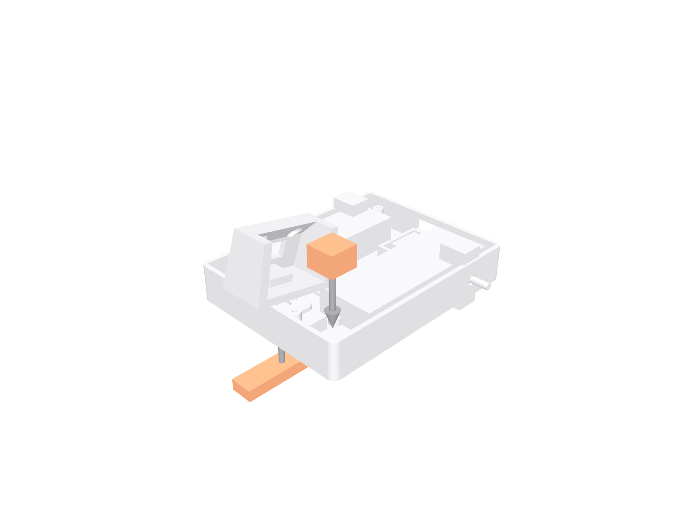
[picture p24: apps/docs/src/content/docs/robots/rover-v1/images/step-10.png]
Step 10: Line sensors + beeper


The line board clips under the front lip with its sensors facing the floor. The beeper drops into its pocket — a dab of glue or tape holds it if loose.

## Step 11 — Wheels + lid

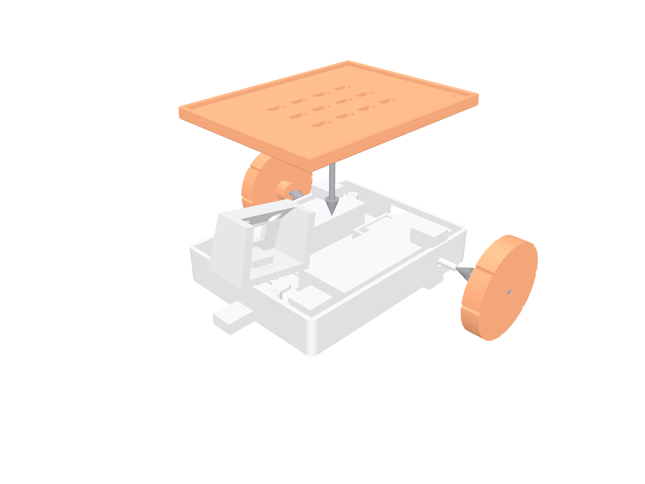
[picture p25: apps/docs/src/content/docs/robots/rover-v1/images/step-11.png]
Step 11: Wheels + lid


Push each wheel straight onto its motor's D-shaped shaft — a firm press

Fasteners for this step:

- M2×6 self-tapping screw x2 — M2 x 6 mm pan head, self-tapping, for printed plastic

That's the hardware done. Next stop: [flash the firmware](./flash/).

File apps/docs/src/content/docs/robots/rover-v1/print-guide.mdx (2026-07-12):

---
title: "Print the parts"
description: "Print settings and filament/time estimates for Rover\u0027s printed parts."
sidebar:
  order: 4
---

All of Rover's printed parts are designed to print **without
supports**: no overhang tricks, no rafts, no glue. Any well-tuned FDM printer
with a 0.4 mm nozzle can produce them.

## Settings

Use the `pla-0.20` profile that ships with this robot, or dial in the same
values by hand:

- **Layer height:** 0.2 mm
- **Walls / perimeters:** 3
- **Infill:** 15% gyroid
- **Supports:** none — every part is support-free by design
- Print each part flat on the bed in its default orientation.

## Parts

| Part | Qty | Material | Color role | Filament (per part) | Time (per part) |
| --- | --- | --- | --- | --- | --- |
| `chassis` | 1 | PLA | body | estimate pending | estimate pending |
| `wheel` | 2 | PLA | accent | estimate pending | estimate pending |
| `caster_mount` | 1 | PLA | body | estimate pending | estimate pending |
| `head` | 1 | PLA | accent | estimate pending | estimate pending |
| `lid` | 1 | PLA | body | estimate pending | estimate pending |

The **color role** column tells you which filament color each part uses: keep
all `body` parts one color and all `accent` parts another, and the robot will
look the way it does on the site — but this is your build, so any palette goes.

When everything is off the bed, check each part against the photos in the
[assembly guide](./assemble/), then move on to [wiring](./wiring/).

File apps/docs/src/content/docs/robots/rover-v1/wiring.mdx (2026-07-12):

---
title: "Wire it up"
description: "The wiring diagram and wire list for Rover."
sidebar:
  order: 5
---

Every connection in Rover uses simple push-on jumper wires — no
soldering iron required. Wire colors in the diagram match the colors in the
wire list, so you can check your work at a glance.

## Wiring diagram

Wiring diagram for Rover

## Wire list

| From | To | Color | Length (mm) |
| --- | --- | --- | --- |
| `pwr.5v` | `core.5v` | RD | 60 |
| `pwr.gnd` | `core.gnd` | BK | 60 |
| `pwr.5v` | `mdrv.vcc` | RD | 50 |
| `pwr.gnd` | `mdrv.gnd` | BK | 50 |
| `sw.a` | `pwr.out_switch_a` | WH | 40 |
| `sw.b` | `pwr.out_switch_b` | GY | 40 |
| `core.gpio4` | `mdrv.ain1` | YE | 70 |
| `core.gpio5` | `mdrv.ain2` | OG | 70 |
| `core.gpio6` | `mdrv.bin1` | GN | 70 |
| `core.gpio7` | `mdrv.bin2` | BU | 70 |
| `core.gpio15` | `mdrv.slp` | WH | 70 |
| `mdrv.aout1` | `motor_left.m1` | RD | 55 |
| `mdrv.aout2` | `motor_left.m2` | BK | 55 |
| `mdrv.bout1` | `motor_right.m1` | RD | 55 |
| `mdrv.bout2` | `motor_right.m2` | BK | 55 |
| `core.gpio8` | `range.sda` | BU | 80 |
| `core.gpio9` | `range.scl` | YE | 80 |
| `core.3v3` | `range.vcc` | RD | 80 |
| `core.gnd` | `range.gnd` | BK | 80 |
| `core.gpio1` | `line.out_l` | BU | 90 |
| `core.gpio2` | `line.out_r` | GN | 90 |
| `core.3v3` | `line.vcc` | RD | 90 |
| `core.gnd` | `line.gnd` | BK | 90 |
| `core.gpio38` | `eyes.din` | GN | 100 |
| `core.5v` | `eyes.vcc` | RD | 100 |
| `core.gnd` | `eyes.gnd` | BK | 100 |
| `core.gpio16` | `buzz.sig` | YE | 60 |
| `core.gnd` | `buzz.gnd` | BK | 60 |

Cut or buy jumper wires a little longer than listed — slack is easier to tuck
away than a wire that is 5 mm too short. When everything matches the diagram,
continue to [assembly](./assemble/).

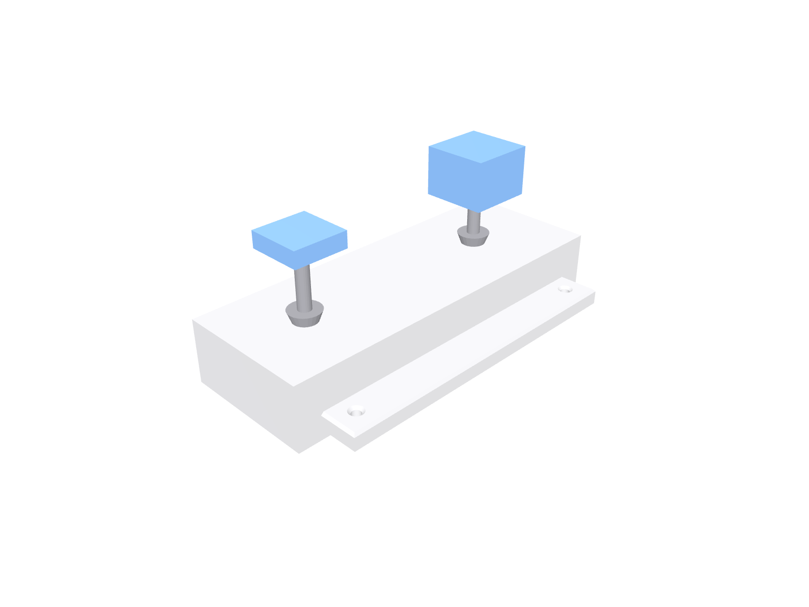
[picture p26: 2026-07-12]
apps/docs/src/content/docs/robots/_test-min/images/step-02.png

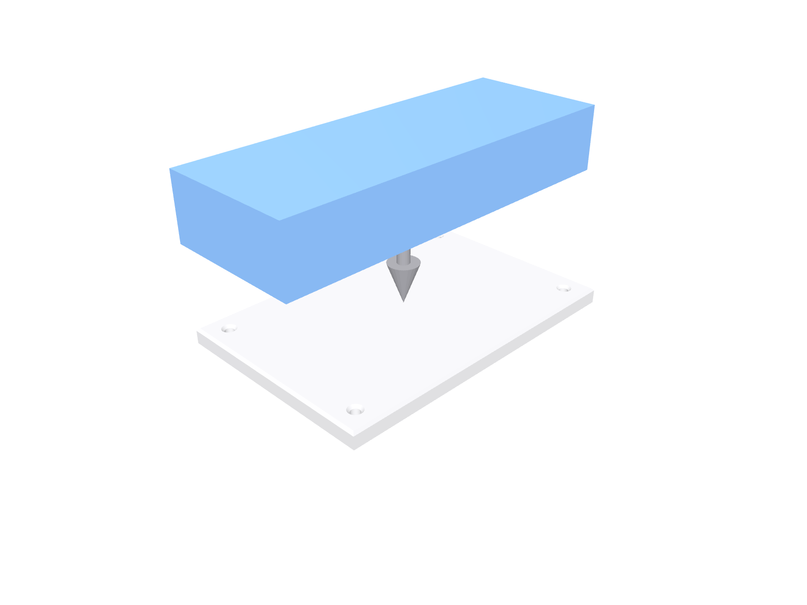
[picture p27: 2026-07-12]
apps/docs/src/content/docs/robots/_test-min/images/step-01.png

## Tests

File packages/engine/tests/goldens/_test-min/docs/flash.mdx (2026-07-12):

---
title: "Flash the firmware"
description: "Put the universal BOTFORGE firmware on Test Min from your browser."
sidebar:
  order: 7
---

Test Min runs the **universal BOTFORGE firmware**: one firmware image
shared by every robot, told what it is by a small config file. The config —
which motors, sensors and LEDs are on which pins — was generated from this
robot's design, so there is nothing to program and nothing to edit. Flashing
happens right in your browser; no toolchains, no drivers to hunt down.

Use a Chromium-based browser (Chrome or Edge) on a laptop or desktop — browser
flashing uses WebSerial, which phones and Safari don't support.

## Step 1 — Plug in over USB

Connect the robot's brain board to your computer with a **data-capable USB-C
cable**. If the board offers two ports, use the one labelled **USB** (not
UART). The power switch can stay off — the board runs from USB while flashing.

## Step 2 — Hold BOOT

Hold down the board's **BOOT** button, tap **RESET** (or re-plug the cable
while still holding BOOT), then release. This puts the chip in download mode
so the browser is allowed to write firmware to it.

## Step 3 — Flash from the site

Open the [/flash](/flash/) page on the site, pick **Test Min**, and
click **Flash**. Choose the board's serial port in the browser prompt and
wait for the progress bar — about a minute. The robot reboots by itself when
flashing finishes.

That's it. The firmware and this robot's config are now on the board —
continue to [first run](./first-run/) to get it on your Wi-Fi.

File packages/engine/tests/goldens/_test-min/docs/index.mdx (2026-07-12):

---
title: "Build the Test Min"
description: "Minimal fixture robot for golden tests."
sidebar:
  order: 1
---

**Minimal fixture robot for golden tests.**

| | |
| --- | --- |
| Difficulty | beginner |
| Build time | about 10 minutes |
| Guide version | 1.0.0 |

## What you'll build

Test Min is a robot you make yourself: you print its plastic parts,
order a handful of low-cost electronic modules, screw and press everything
together, then flash the firmware straight from your browser. When it wakes up
you drive it from your phone and teach it new tricks with a block-based
behavior builder — no soldering station or programming experience required.

## How this guide works

Work through the pages in order — each one is a short, self-contained step:

1. [Safety first](./safety/) — read this before anything else.
2. [Source the parts](./source-parts/) — everything to buy, with links.
3. [Print the parts](./print-guide/) — settings and estimates for each piece.
4. [Wire it up](./wiring/) — the wiring diagram and wire list.
5. [Assemble](./assemble/) — step-by-step, LEGO style.
6. [Flash the firmware](./flash/) — from your browser, no tools to install.
7. [First run](./first-run/) — get Test Min on your Wi-Fi and drive it.
8. [Play and program](./play/) — build behaviors with blocks.
9. [Troubleshooting](./troubleshooting/) — when something doesn't work.

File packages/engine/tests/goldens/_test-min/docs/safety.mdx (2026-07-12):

---
title: "Safety first"
description: "Read this before building Test Min \u2014 batteries, small parts and USB power."
sidebar:
  order: 2
---

Building Test Min is safe when you follow a few simple rules. Read this
page before you order, print or assemble anything.

## Who can build this

This project is designed for builders **age 14 and up**. Younger makers are
very welcome — with an adult alongside for the battery, tools and small parts.

## Small parts and pinch points

- Screws, the caster ball and sensor boards are **small parts** — keep them
  away from young children and pets.
- Motors and wheels can **pinch fingers and pull in hair**. Keep hands clear of
  the wheels while the robot is powered, and switch it off before picking it up
  for adjustments.
- Freshly printed parts can have sharp edges. Deburr them with light sanding
  before assembly.

## The battery — read this twice

Test Min runs from a single lithium cell, and lithium cells demand
respect:

- **We never ship lithium batteries.** Buy a **protected 18650 cell** from a
  reputable local supplier, together with a **quality single-cell USB-C
  charger**. "Protected" means the cell has a built-in cut-off against
  over-discharge and short circuits — it is worth the extra dollar.
- **Never charge a cell unattended** and never charge it overnight. Charge on
  a hard, non-flammable surface, away from anything that burns.
- Stop using any cell that is dented, punctured, swollen or gets hot at rest,
  and recycle it at a battery drop-off point — never in household trash.
- Mind the polarity when inserting the cell. Reversed cells can destroy the
  electronics and heat up fast.

## USB power

- While flashing and testing you can power the robot from a computer USB port
  — no battery needed. This is the safest way to do the first bring-up.
- Use a **data-capable USB-C cable** (many cheap cables are charge-only).
- Don't drive the motors hard on USB power alone: a laptop port can brown-out,
  which resets the robot mid-run. Use the battery for real driving.

With that covered, on to the fun part: [sourcing the parts](./source-parts/).

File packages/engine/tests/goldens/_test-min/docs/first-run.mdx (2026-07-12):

---
title: "First run"
description: "Get Test Min onto your Wi-Fi and take it for its first drive."
sidebar:
  order: 8
---

Time to wake Test Min up and get it onto your Wi-Fi. You only do this
once — the robot remembers your network afterwards.

## 1. Join the robot's setup hotspot

Flip the power switch on. On first boot the robot opens its own Wi-Fi hotspot
named `Botforge-XXXX` (the XXXX is unique to your robot). Join it from your
phone or laptop — a **captive portal** setup page pops up automatically, like
hotel Wi-Fi. If it doesn't appear, open a browser and go to any http page.

## 2. Pick your Wi-Fi and name your robot

In the portal, choose your home Wi-Fi network, enter its password, and give
your robot a name. The name becomes its address on your network, so keep it
simple — lowercase, no spaces. The portal also shows the robot's IP address
and a QR code once it connects: **note the IP down**, it's handy later.

## 3. Say hello

Once the robot joins your network, open:

```
http://<name>.local
```

…replacing `<name>` with the name you chose.

:::note[iPhone or iPad?]
iOS is picky about `.local` (mDNS) addresses and sometimes refuses to resolve
them. If the page won't load, use the **IP address shown in the setup portal**
instead — e.g. `http://192.168.1.42`.
:::

## 4. Take it for a spin

Head to the [/drive](/drive/) page on the site, connect to your robot, and
drive it around with the on-screen joystick. Driving stops instantly when you
let go — that's the built-in deadman safety.

## Factory reset

Robot moving to a new Wi-Fi network, or typo in the password? Hold the
**BOOT** button for **5 seconds** while the robot is on. It forgets its Wi-Fi
settings and returns to the `Botforge-XXXX` setup hotspot, ready for step 1
again.

All good? Go teach it some tricks on the [play page](./play/).

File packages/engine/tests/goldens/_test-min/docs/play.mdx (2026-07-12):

---
title: "Play and program"
description: "Drive Test Min and build new behaviors with blocks."
sidebar:
  order: 9
---

Driving is fun; programming is better. Test Min is programmed with
**blocks** — snap together events, moves, sounds and lights in the
[/builder](/builder/) page on the site, no code required. Behind the scenes
each block program compiles to a tiny behavior file the robot runs entirely
on its own — no phone or laptop needed once it's loaded.

## Behaviors that ship with Test Min

| Behavior | Name | Autostarts |
| --- | --- | --- |
| `blink` | blink | yes |

The autostart behavior runs whenever the robot powers on. Open any of these in
the builder to see how they work — remixing a shipped behavior is the fastest
way to learn.

## Send a behavior to your robot

1. Build (or remix) a behavior in the [/builder](/builder/).
2. Try it in the built-in simulator — same blocks, zero risk of driving off a
   table.
3. Click **Send to robot**, pick your robot on the network, and it uploads in
   a blink.
4. Run it from the builder, or mark it **autostart** so it runs every time the
   robot switches on.

If the robot doesn't show up in the send dialog, check the
[troubleshooting](./troubleshooting/) page.

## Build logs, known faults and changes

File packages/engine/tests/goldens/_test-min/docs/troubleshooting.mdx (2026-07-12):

---
title: "Troubleshooting"
description: "Symptoms and fixes for every module in Test Min."
sidebar:
  order: 10
---

Something's off? Find the module that's misbehaving below — each section lists
the symptoms we see most and the fix that almost always works.

## ESP32-S3-DevKitC-1 dev board (N8R2)

### Computer doesn't see the board over USB

Use a USB-C cable that carries data (many only charge), and plug into the port labelled USB, not UART.

### Upload fails or times out

Hold the BOOT button while plugging in the cable, then try the upload again.

## 2-pixel WS2812 LED eyes

### Eyes stay dark

Data must enter at the pin marked DIN (the arrows point away from it) — if the wire is on DOUT, move it to the other end.

### Colours look wrong

Some boards use a different colour order — swap the red/green channel order in the builder's LED settings.

## Passive piezo buzzer

### No sound at all

Check the + leg (the longer one, marked on top) goes to the yellow signal wire, and that yours is a PASSIVE buzzer — active ones only play one fixed tone.

### Sound is very quiet

Seat the buzzer fully in its pocket and make sure the small hole on top isn't covered.

## General

### Robot won't turn on

Check the power switch is in the on position, then check the cell: charge it
fully and make sure it is seated the right way around. If the robot runs on
USB but not on battery, the cell (or its protection circuit) is the culprit.

### Can't find the robot on the network

Your robot and your phone/laptop must be on the **same Wi-Fi network**. If
they are and it still doesn't appear, re-provision: hold **BOOT** for 5
seconds to factory-reset Wi-Fi, then run the [first-run setup](./first-run/)
again. On iOS, prefer the robot's IP address over the `.local` name.

Still stuck? Take a photo of your wiring next to the
[wiring diagram](./wiring/) — nine times out of ten the answer is in that
comparison.

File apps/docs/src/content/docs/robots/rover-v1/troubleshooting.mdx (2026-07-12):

---
title: "Troubleshooting"
description: "Symptoms and fixes for every module in Rover."
sidebar:
  order: 10
---

Something's off? Find the module that's misbehaving below — each section lists
the symptoms we see most and the fix that almost always works.

## ESP32-S3-DevKitC-1 dev board (N8R2)

### Computer doesn't see the board over USB

Use a USB-C cable that carries data (many only charge), and plug into the port labelled USB, not UART.

### Upload fails or times out

Hold the BOOT button while plugging in the cable, then try the upload again.

## 1S Li-ion power board (charger + 5V boost)

### Robot won't turn on

Check the 18650 is inserted with + facing the mark, the slide switch is on, and the cell has charge — plug in USB-C and look for the charging light.

### Robot dies the moment the motors start

The cell is nearly empty or worn out — charge it fully, or try a known-good branded protected cell.

## DRV8833 dual motor driver

### One wheel spins the wrong way

Swap that motor's two wires at the driver, or flip its +/- in the builder's motor settings.

### Motors twitch or robot reboots when driving

Battery is low or wires too thin — charge the cell and check the 5V/GND wires are seated.

## N20 metal-gear motor (6V 150RPM)

### One wheel never spins

Check both motor wires are firmly seated at the driver board and that the thin solder tabs on the motor haven't snapped off.

### Motor whirrs but the wheel barely moves

Push the wheel further onto the D-shaped shaft until it seats — it should not slip when you twist it by hand.

## VL53L0X time-of-flight distance sensor

### Distance always reads 0 or a huge number

SDA and SCL are probably swapped — swap the blue and yellow wires at the brain.

### Readings are jumpy or too short

Peel the tiny protective film off the sensor window and keep wires out of its view.

## 2-channel TCRT5000 line sensor

### Robot ignores the line

Keep the sensors 2-5 mm above the floor and use dark tape on a light surface — faint or glossy lines won't register.

### Readings jump around

Bright sunlight and halogen lamps blind infrared sensors — try a shadier spot.

## 2-pixel WS2812 LED eyes

### Eyes stay dark

Data must enter at the pin marked DIN (the arrows point away from it) — if the wire is on DOUT, move it to the other end.

### Colours look wrong

Some boards use a different colour order — swap the red/green channel order in the builder's LED settings.

## Passive piezo buzzer

### No sound at all

Check the + leg (the longer one, marked on top) goes to the yellow signal wire, and that yours is a PASSIVE buzzer — active ones only play one fixed tone.

### Sound is very quiet

Seat the buzzer fully in its pocket and make sure the small hole on top isn't covered.

## SPDT slide switch

### Switch does nothing

Solder to the MIDDLE pin plus one outer pin — the two outer pins are never connected to each other.

### Robot flickers when you touch the switch

A solder joint is loose — reheat both joints until the solder flows shiny and smooth.

## General

### Robot won't turn on

Check the power switch is in the on position, then check the cell: charge it
fully and make sure it is seated the right way around. If the robot runs on
USB but not on battery, the cell (or its protection circuit) is the culprit.

### Can't find the robot on the network

Your robot and your phone/laptop must be on the **same Wi-Fi network**. If
they are and it still doesn't appear, re-provision: hold **BOOT** for 5
seconds to factory-reset Wi-Fi, then run the [first-run setup](./first-run/)
again. On iOS, prefer the robot's IP address over the `.local` name.

Still stuck? Take a photo of your wiring next to the
[wiring diagram](./wiring/) — nine times out of ten the answer is in that
comparison.

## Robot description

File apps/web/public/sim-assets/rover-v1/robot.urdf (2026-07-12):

<?xml version="1.0" ?>
<robot name="rover-v1">
  <link name="chassis">
    <inertial>
      <origin xyz="0 0 0.008" rpy="0 0 0" />
      <mass value="0.0376877" />
      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
    </inertial>
    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
  </link>
  <link name="motor_left">
    <inertial>
      <origin xyz="0 0 0" rpy="0 0 0" />
      <mass value="0.0095" />
      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
    </inertial>
    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
  </link>
  <link name="motor_right">
    <inertial>
      <origin xyz="0 0 0" rpy="0 0 0" />
      <mass value="0.0095" />
      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
    </inertial>
    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
  </link>
  <link name="wheel_1">
    <inertial>
      <origin xyz="0 0 0.007" rpy="0 0 0" />
      <mass value="0.0141252" />
      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
    </inertial>
    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
  </link>
  <link name="wheel_2">
    <inertial>
      <origin xyz="0 0 0.007" rpy="0 0 0" />
      <mass value="0.0141252" />
      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
    </inertial>
    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
  </link>
  <link name="caster_mount">
    <inertial>
      <origin xyz="0 0 0.004" rpy="0 0 0" />
      <mass value="0.00253952" />
      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
    </inertial>
    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
  </link>
  <link name="m3_ball_6mm">
    <inertial>
      <origin xyz="0 0 0" rpy="0 0 0" />
      <mass value="0.001" />
      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
    </inertial>
    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
  </link>
  <link name="mdrv">
    <inertial>
      <origin xyz="0 0 0" rpy="0 0 0" />
      <mass value="0.002" />
      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
    </inertial>
    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
  </link>
  <link name="pwr">
    <inertial>
      <origin xyz="0 0 0" rpy="0 0 0" />
      <mass value="0.025" />
      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
    </inertial>
    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
  </link>
  <link name="sw">
    <inertial>
      <origin xyz="0 0 0" rpy="0 0 0" />
      <mass value="0.001" />
      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
    </inertial>
    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
  </link>
  <link name="core">
    <inertial>
      <origin xyz="0 0 0" rpy="0 0 0" />
      <mass value="0.01" />
      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
    </inertial>
    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
  </link>
  <link name="range">
    <inertial>
      <origin xyz="0 0 0" rpy="0 0 0" />
      <mass value="0.001" />
      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
    </inertial>
    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
  </link>
  <link name="line">
    <inertial>
      <origin xyz="0 0 0" rpy="0 0 0" />
      <mass value="0.003" />
      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
    </inertial>
    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
  </link>
  <link name="eyes">
    <inertial>
      <origin xyz="0 0 0" rpy="0 0 0" />
      <mass value="0.001" />
      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
    </inertial>
    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
  </link>
  <link name="buzz">
    <inertial>
      <origin xyz="0 0 0" rpy="0 0 0" />
      <mass value="0.002" />
      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
    </inertial>
    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
  </link>
  <link name="head">
    <inertial>
      <origin xyz="0 0 0.012" rpy="0 0 0" />
      <mass value="0.00757252" />
      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
    </inertial>
    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
  </link>
  <link name="lid">
    <inertial>
      <origin xyz="0 0 0.0025" rpy="0 0 0" />
      <mass value="0.024065" />
      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
    </inertial>
    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
  </link>
  <joint name="buzz_joint" type="fixed">
    <parent link="chassis" />
    <child link="buzz" />
    <origin xyz="0.032 0.02 0.006" rpy="0 0 0" />
  </joint>
  <joint name="caster_mount_joint" type="fixed">
    <parent link="chassis" />
    <child link="caster_mount" />
    <origin xyz="0.038 0 0.002" rpy="0 0 0" />
  </joint>
  <joint name="core_joint" type="fixed">
    <parent link="chassis" />
    <child link="core" />
    <origin xyz="-0.01 0.018 0.008" rpy="0 0 0" />
  </joint>
  <joint name="eyes_joint" type="fixed">
    <parent link="chassis" />
    <child link="eyes" />
    <origin xyz="0.042 0 0.024" rpy="0 -0.174533 0" />
  </joint>
  <joint name="head_joint" type="fixed">
    <parent link="chassis" />
    <child link="head" />
    <origin xyz="0.04 0 0.018" rpy="0 -0.174533 0" />
  </joint>
  <joint name="lid_joint" type="fixed">
    <parent link="chassis" />
    <child link="lid" />
    <origin xyz="0 0 0.026" rpy="0 0 0" />
  </joint>
  <joint name="line_joint" type="fixed">
    <parent link="chassis" />
    <child link="line" />
    <origin xyz="0.04 0 0.002" rpy="0 0 0" />
  </joint>
  <joint name="m3_ball_6mm_joint" type="fixed">
    <parent link="chassis" />
    <child link="m3_ball_6mm" />
    <origin xyz="0.038 0 0" rpy="0 0 0" />
  </joint>
  <joint name="mdrv_joint" type="fixed">
    <parent link="chassis" />
    <child link="mdrv" />
    <origin xyz="-0.038 0 0.006" rpy="0 0 0" />
  </joint>
  <joint name="motor_left_joint" type="fixed">
    <parent link="chassis" />
    <child link="motor_left" />
    <origin xyz="-0.028 0.03 0.008" rpy="0 0 1.5708" />
  </joint>
  <joint name="motor_right_joint" type="fixed">
    <parent link="chassis" />
    <child link="motor_right" />
    <origin xyz="-0.028 -0.03 0.008" rpy="0 0 -1.5708" />
  </joint>
  <joint name="pwr_joint" type="fixed">
    <parent link="chassis" />
    <child link="pwr" />
    <origin xyz="0 -0.022 0.008" rpy="0 0 0" />
  </joint>
  <joint name="range_joint" type="fixed">
    <parent link="chassis" />
    <child link="range" />
    <origin xyz="0.042 0 0.02" rpy="0 -0.174533 0" />
  </joint>
  <joint name="sw_joint" type="fixed">
    <parent link="chassis" />
    <child link="sw" />
    <origin xyz="-0.02 -0.034 0.01" rpy="0 0 0" />
  </joint>
  <joint name="wheel_1_joint" type="continuous">
    <parent link="chassis" />
    <child link="wheel_1" />
    <origin xyz="-0.028 0.044 0.008" rpy="1.5708 0 0" />
    <axis xyz="0 -1 0" />
  </joint>
  <joint name="wheel_2_joint" type="continuous">
    <parent link="chassis" />
    <child link="wheel_2" />
    <origin xyz="-0.028 -0.044 0.008" rpy="-1.5708 0 0" />
    <axis xyz="0 1 0" />
  </joint>
</robot>

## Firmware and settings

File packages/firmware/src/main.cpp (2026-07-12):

/**
 * botforge firmware — universal ESP32-S3 robot firmware (PLAN Phase 2).
 *
 * Boot sequence (PLAN Phase 2 structure):
 *   LittleFS -> Config (/config.json, /wifi.json) -> drivers from
 *   config.json modules[] (Factory, P2) -> Net (STA join or provisioning
 *   AP, §5.4) -> HTTP API (:80) + WS server (:81/ws) -> Behavior VM
 *   autostart (P8 — the robot runs with no connection at all).
 *
 * The Behavior VM lives in vm/Vm.h (a concurrent Phase-2 module); this file
 * codes against its frozen API and bridges VmHal to the driver registry:
 * sensor names like "range.mm" route to instance "range", field "mm".
 *
 * The whole file is compiled out for the native (host) test environment.
 */
#ifndef NATIVE_BUILD

#include <Arduino.h>
#include <ArduinoJson.h>
#include <LittleFS.h>

#include <string>

#include "core/BootButton.h"
#include "core/Config.h"
#include "core/HttpApi.h"
#include "core/Log.h"
#include "core/ModuleRegistry.h"
#include "core/Net.h"
#include "core/Ota.h"
#include "core/Version.h"
#include "core/WsServer.h"
#include "drivers/Factory.h"
#include "vm/Vm.h"

using namespace botforge;

// ---------------------------------------------------------------------------
// Globals (single-threaded Arduino loop; no locking needed)
// ---------------------------------------------------------------------------

static Config g_config;
static ModuleRegistry g_modules;
static Net g_net;
static HttpApi g_http;
static WsServer g_ws;
static Vm g_vm;
static BootButton g_bootButton;  // short press -> on_button; 5 s -> wifi wipe

// The VM references the behavior JSON during load; keep the buffer alive for
// the lifetime of the loaded program.
static std::string g_behaviorJson;

// ---------------------------------------------------------------------------
// VmHal bridge: BSJ ops -> driver registry (P2: fully generic routing)
// ---------------------------------------------------------------------------

struct DriverHal final : public VmHal {
  void drive(int l, int r) override {
    JsonDocument d;
    d["l"] = l;
    d["r"] = r;
    g_modules.actAll("drive", d.as<JsonObjectConst>());
  }

  void servo(const char* id, int deg) override {
    IModule* mod = g_modules.find(id);
    if (mod == nullptr) return;
    JsonDocument d;
    d["deg"] = deg;
    mod->act("servo", d.as<JsonObjectConst>());
  }

  void led(int r, int g, int b, int id) override {
    JsonDocument d;
    d["r"] = r;
    d["g"] = g;
    d["b"] = b;
    if (id >= 0) d["id"] = id;  // id < 0 = all pixels (§5.3 "id omitted")
    g_modules.actAll("led", d.as<JsonObjectConst>());
  }

  void ledOff(int id) override {
    JsonDocument d;
    if (id >= 0) d["id"] = id;
    g_modules.actAll("led_off", d.as<JsonObjectConst>());
  }

  void tone(int hz, int ms) override {
    JsonDocument d;
    d["hz"] = hz;
    d["ms"] = ms;
    g_modules.actAll("tone", d.as<JsonObjectConst>());
  }

  float readSensor(const char* name) override {
    // "<instance>.<field>" (e.g. "range.mm", "line.l") per §5.3.
    float v = 0.0f;
    return g_modules.readField(name, v) ? v : 0.0f;
  }

  void log(int level, const char* msg) override {
    LogLevel lvl = level <= 0   ? LOG_DEBUG
                   : level == 1 ? LOG_INFO
                   : level == 2 ? LOG_WARN
                                : LOG_ERROR;
    logf(lvl, "%s", msg);
  }

  long random(long lo, long hi) override {
    // BSJ {"rand": [min, max]} is inclusive on both ends (Appendix B uses
    // rand [0,1] as a coin flip); Arduino random() excludes the upper bound.
    return ::random(lo, hi + 1);
  }
};

static DriverHal g_hal;

// ---------------------------------------------------------------------------
// Behavior control (shared by HTTP /api/behavior*, WS mode switch, autostart)
// ---------------------------------------------------------------------------

static void stopMotors() {
  JsonDocument empty;
  g_modules.actAll("stop", empty.as<JsonObjectConst>());
}

static bool startBehaviorFromBuffer(uint32_t now) {
  if (g_behaviorJson.empty()) {
    logf(LOG_WARN, "behavior: nothing loaded");
    return false;
  }
  if (!g_vm.load(g_behaviorJson.c_str(), g_behaviorJson.size(), &g_hal)) {
    const char* err = g_vm.error();
    logf(LOG_ERROR, "behavior: load failed: %s",
         err != nullptr ? err : "unknown");
    return false;
  }
  g_vm.start(now);
  logf(LOG_INFO, "behavior: running");
  return true;
}

static bool behaviorUpload(const char* json, size_t len, bool run) {
  if (!g_config.saveBehavior(json, len)) return false;
  g_behaviorJson.assign(json, len);
  if (run) {
    g_vm.stop();
    stopMotors();
    return startBehaviorFromBuffer(millis());
  }
  return true;
}

static bool behaviorCtl(const char* action) {
  if (strcmp(action, "run") == 0) {
    if (g_behaviorJson.empty() && !g_config.loadBehavior(g_behaviorJson)) {
      return false;
    }
    g_vm.stop();
    stopMotors();
    return startBehaviorFromBuffer(millis());
  }
  if (strcmp(action, "stop") == 0) {
    g_vm.stop();
    stopMotors();
    logf(LOG_INFO, "behavior: stopped");
    return true;
  }
  if (strcmp(action, "autostart_on") == 0) {
    g_config.setAutostartEnabled(true);
    return true;
  }
  if (strcmp(action, "autostart_off") == 0) {
    g_config.setAutostartEnabled(false);
    return true;
  }
  return false;
}

// ---------------------------------------------------------------------------
// Boot
// ---------------------------------------------------------------------------

void setup() {
  Serial.begin(115200);
  delay(300);  // give USB-CDC a moment so the boot banner is visible
  logf(LOG_INFO, "botforge fw %s booting", BOTFORGE_FW_VERSION);

  // 1. Filesystem + config.
  if (!LittleFS.begin(true /* format on first mount */)) {
    logf(LOG_ERROR, "littlefs: mount failed — no config or portal available");
  }
  g_config.loadFromFs();
  logf(LOG_INFO, "config: robot %s (cfg_hash %s, %u modules)",
       g_config.robotId(), g_config.cfgHash(),
       static_cast<unsigned>(g_config.moduleCount()));

  // 2. Drivers from config.json modules[] (P2 — the config IS the robot).
  analogReadResolution(12);
  for (size_t i = 0; i < g_config.moduleCount(); ++i) {
    JsonObjectConst m = g_config.module(i);
    const char* id = m["id"] | "";
    const char* driver = m["driver"] | "";
    IModule* mod = createDriver(driver);
    if (mod == nullptr) {
      logf(LOG_WARN, "driver: %s (%s) unknown — skipped", driver, id);
      continue;
    }
    if (!mod->begin(m)) {
      logf(LOG_ERROR, "driver: %s (%s) begin failed — disabled", driver, id);
      delete mod;
      continue;
    }
    if (!g_modules.add(id, driver, mod)) {
      logf(LOG_ERROR, "driver: registry full, %s dropped", id);
      delete mod;
      continue;
    }
    logf(LOG_INFO, "driver: %s ready (%s)", id, driver);
  }

  // 3. Connectivity (STA join or provisioning AP) + servers.
  g_net.begin(g_config);

  HttpApi::BehaviorCtl ctl;
  ctl.upload = behaviorUpload;
  ctl.ctl = behaviorCtl;
  g_http.begin(g_config, g_net, ctl);
  g_net.registerPortalRoutes(g_http.server());

  WsServer::VmHooks hooks;
  hooks.startBehavior = []() {
    if (g_vm.running()) return;
    if (g_behaviorJson.empty()) g_config.loadBehavior(g_behaviorJson);
    startBehaviorFromBuffer(millis());
  };
  hooks.stopBehavior = []() {
    g_vm.stop();
    stopMotors();
  };
  hooks.behaviorRunning = []() { return g_vm.running(); };
  g_ws.begin(g_config, g_net, g_modules, hooks);

  // Forward every log line to WS clients (outbound `log` message, §5.4).
  logger().setSink(
      [](void* ctx, LogLevel level, uint32_t ms, const char* msg) {
        (void)ms;
        static_cast<WsServer*>(ctx)->broadcastLog(level, msg);
      },
      &g_ws);

  // 4. Optional OTA check-on-boot (config-flagged; Phase 2.6).
  Ota::checkOnBoot(g_config);

  // 5. Behavior VM autostart (P8: runs without any connection).
  if (g_config.autostartEnabled() && g_config.loadBehavior(g_behaviorJson)) {
    if (startBehaviorFromBuffer(millis())) {
      logf(LOG_INFO, "behavior: autostarted");
    }
  }

  pinMode(0, INPUT_PULLUP);  // BOOT button (short = on_button, 5 s = wipe)
  logf(LOG_INFO, "boot complete, free heap %u B",
       static_cast<unsigned>(ESP.getFreeHeap()));
}

// ---------------------------------------------------------------------------
// Main loop
// ---------------------------------------------------------------------------

void loop() {
  uint32_t now = millis();

  g_net.tick(now);         // DNS (portal) + scheduled reboots
  g_http.tick();           // HTTP API
  g_ws.tick(now);          // WS, deadman, 5 Hz telemetry
  g_modules.tickAll(now);  // drivers: slew, servo stagger, sensor polls
  g_vm.tick(now);          // behavior VM scheduler

  BootButton::Event ev = g_bootButton.update(digitalRead(0) == LOW, now);
  if (ev == BootButton::ShortPress) {
    g_vm.onButton(now);  // §5.3 on_button event
  } else if (ev == BootButton::LongHold) {
    logf(LOG_WARN, "boot: held 5 s — wiping wifi creds + reboot (§5.4)");
    stopMotors();
    g_config.wipeWifi();
    delay(300);
    ESP.restart();
  }

  delay(1);  // yield to Wi-Fi/RTOS
}

#endif  // NATIVE_BUILD

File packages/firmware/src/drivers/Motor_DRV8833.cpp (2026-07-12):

#ifndef NATIVE_BUILD

#include "Motor_DRV8833.h"

#include <Arduino.h>

#include "../core/Log.h"

namespace botforge {

namespace {

float clampPower(float v) {
  if (v < -100.0f) return -100.0f;
  if (v > 100.0f) return 100.0f;
  return v;
}

}  // namespace

bool Motor_DRV8833::begin(JsonObjectConst cfg) {
  JsonObjectConst pins = cfg["pins"];
  ain1_ = pins["ain1"] | -1;
  ain2_ = pins["ain2"] | -1;
  bin1_ = pins["bin1"] | -1;
  bin2_ = pins["bin2"] | -1;
  slp_ = pins["slp"] | -1;
  if (ain1_ < 0 || ain2_ < 0 || bin1_ < 0 || bin2_ < 0) {
    logf(LOG_ERROR, "drv8833: missing pwm pins");
    return false;
  }

  JsonObjectConst params = cfg["params"];
  pwmHz_ = params["pwm_hz"] | 20000u;
  float slewPerS = params["slew_per_s"] | 400.0f;
  slewL_.configure(slewPerS);
  slewR_.configure(slewPerS);

  const int pwmPins[4] = {ain1_, ain2_, bin1_, bin2_};
  for (int pin : pwmPins) {
    if (!ledcAttach(static_cast<uint8_t>(pin), pwmHz_, kPwmResolutionBits)) {
      logf(LOG_ERROR, "drv8833: ledcAttach failed on gpio%d", pin);
      return false;
    }
    ledcWrite(static_cast<uint8_t>(pin), 0);
  }
  if (slp_ >= 0) {
    pinMode(slp_, OUTPUT);
    digitalWrite(slp_, HIGH);  // enable the H-bridge
  }
  ready_ = true;
  return true;
}

void Motor_DRV8833::tick(uint32_t now) {
  if (!ready_) return;
  if (!haveTick_) {
    haveTick_ = true;
    lastTick_ = now;
    return;
  }
  uint32_t dt = now - lastTick_;
  lastTick_ = now;
  if (dt == 0) return;

  float l = slewL_.update(targetL_, dt);
  float r = slewR_.update(targetR_, dt);
  applyChannel(ain1_, ain2_, l);
  applyChannel(bin1_, bin2_, r);
}

bool Motor_DRV8833::read(const char* field, float& out) {
  if (strcmp(field, "l") == 0) {
    out = slewL_.value();
    return true;
  }
  if (strcmp(field, "r") == 0) {
    out = slewR_.value();
    return true;
  }
  return false;
}

bool Motor_DRV8833::act(const char* op, JsonObjectConst params) {
  if (strcmp(op, "drive") == 0) {
    targetL_ = clampPower(params["l"] | 0.0f);
    targetR_ = clampPower(params["r"] | 0.0f);
    return true;
  }
  if (strcmp(op, "stop") == 0) {
    hardStop();
    return true;
  }
  return false;
}

void Motor_DRV8833::hardStop() {
  // Safety path (deadman, VM halt): bypass the slew and cut PWM now.
  targetL_ = 0.0f;
  targetR_ = 0.0f;
  slewL_.reset(0.0f);
  slewR_.reset(0.0f);
  if (!ready_) return;
  applyChannel(ain1_, ain2_, 0.0f);
  applyChannel(bin1_, bin2_, 0.0f);
}

void Motor_DRV8833::applyChannel(int pinFwd, int pinRev, float power) {
  // Fast-decay (coast) drive: forward = PWM on IN1, 0 on IN2; reverse
  // mirrored. A small deadband avoids buzzing the bridge at ~0 power.
  float mag = power < 0 ? -power : power;
  if (mag < 0.5f) {
    ledcWrite(static_cast<uint8_t>(pinFwd), 0);
    ledcWrite(static_cast<uint8_t>(pinRev), 0);
    return;
  }
  if (mag > 100.0f) mag = 100.0f;
  uint32_t duty = static_cast<uint32_t>(mag * kMaxDuty / 100.0f + 0.5f);
  if (power >= 0) {
    ledcWrite(static_cast<uint8_t>(pinFwd), duty);
    ledcWrite(static_cast<uint8_t>(pinRev), 0);
  } else {
    ledcWrite(static_cast<uint8_t>(pinFwd), 0);
    ledcWrite(static_cast<uint8_t>(pinRev), duty);
  }
}

}  // namespace botforge

#endif  // NATIVE_BUILD

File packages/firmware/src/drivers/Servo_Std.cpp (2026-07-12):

#ifndef NATIVE_BUILD

#include "Servo_Std.h"

#include <Arduino.h>

#include "../core/Log.h"

namespace botforge {

int Servo_Std::s_attachCount = 0;

bool Servo_Std::begin(JsonObjectConst cfg) {
  pin_ = cfg["pins"]["sig"] | -1;
  if (pin_ < 0) {
    logf(LOG_ERROR, "servo: missing sig pin");
    return false;
  }
  JsonObjectConst params = cfg["params"];
  minUs_ = params["min_us"] | 500;
  maxUs_ = params["max_us"] | 2400;
  degMin_ = params["deg_min"] | 0.0f;
  degMax_ = params["deg_max"] | 180.0f;
  staggerMs_ = params["attach_stagger_ms"] | 60u;
  pendingDeg_ = (degMin_ + degMax_) * 0.5f;  // center until commanded
  attachSlot_ = s_attachCount++;
  ready_ = true;
  return true;
}

void Servo_Std::tick(uint32_t now) {
  if (!ready_ || attached_) return;
  if (!haveFirstTick_) {
    haveFirstTick_ = true;
    attachAt_ = now + static_cast<uint32_t>(attachSlot_) * staggerMs_;
  }
  if (static_cast<uint32_t>(now - attachAt_) > 0x7fffffffu) return;  // not yet
  // Attach moment reached (unsigned-wrap-safe "now >= attachAt_").
  servo_.setPeriodHertz(50);
  if (servo_.attach(pin_, minUs_, maxUs_) == 0) {
    logf(LOG_ERROR, "servo: attach failed on gpio%d", pin_);
    ready_ = false;
    return;
  }
  attached_ = true;
  writeAngle(pendingDeg_);
}

bool Servo_Std::read(const char* field, float& out) {
  if (strcmp(field, "deg") == 0) {
    out = pendingDeg_;
    return true;
  }
  return false;
}

bool Servo_Std::act(const char* op, JsonObjectConst params) {
  if (strcmp(op, "servo") != 0) return false;
  float deg = params["deg"] | pendingDeg_;
  if (deg < degMin_) deg = degMin_;
  if (deg > degMax_) deg = degMax_;
  pendingDeg_ = deg;
  if (attached_) writeAngle(deg);
  return true;
}

void Servo_Std::writeAngle(float deg) {
  // ESP32Servo maps write(0..180) across [minUs_, maxUs_].
  servo_.write(static_cast<int>(deg + 0.5f));
}

}  // namespace botforge

#endif  // NATIVE_BUILD

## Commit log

2026-07-12 chore: clear repository for BOTFORGE platform build
    Replaces the previous PixelShapeRN contents on this branch with a clean
    slate for the BOTFORGE monorepo, per the attached master build plan.
    Claude-Session: https://claude.ai/code/session_01C8q8Tn9LUMw5NcnYMnpSUF
2026-07-12 Phase 0: BOTFORGE monorepo scaffold and tooling
    - pnpm 10 + Turborepo workspace; prettier/husky/lint-staged
    - apps/web: Next.js 14 + Tailwind placeholder site (build + vitest green)
    - apps/docs: Astro Starlight docs shell awaiting generated robot guides
    - packages/engine: uv Python package, typer CLI 'botforge' stubs, pytest+ruff
    - packages/firmware: PlatformIO esp32s3 (arduino core 3.x via pioarduino,
    8MB dual-OTA+LittleFS partitions) + native Unity test env (green)
    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
    [partitions.csv]
2026-07-12 docs: log Phase 1 contract decisions (pin-type extensions, core GPIO map, CadQuery 2.8)
    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
2026-07-12 Phase 1: module registry, rover-v1 and _test-min robot data
    - 12 launch modules per PLAN $5.1 (drv-8833 + servo-sg90 verbatim, plus
    motor_out/switch output pins per DECISIONS) + fasteners.yaml
    - robots/rover-v1: verbatim robot.yaml, assembly.yaml with plan poses +
    TUNE-marked electronics poses, 3 BSJ behaviors (avoid_obstacles verbatim)
    - robots/_test-min: minimal fixture robot for golden tests
    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
    [motor-n20.yaml, robot.yaml, servo-mg90s.yaml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]
2026-07-12 chore: exclude engine test fixtures/goldens from prettier
    Golden-file comparisons must stay byte-exact; lint-staged must not
    reformat them on commit.
    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
2026-07-12 Phase 1: engine core — models, loader/resolver, validators, CLI
    - pydantic models mirroring PLAN $5.1/$5.2 (+ logged pin-type extensions)
    - registry loader, robot bundle loader, resolver -> manifest.resolved.json
    - validator rules a-j: refs, endpoints, required pins, GPIO double-booking
    (I2C bus exception), ADC1-only, reserved pins, type compatibility,
    2000mA power budget warning, behavior/autostart, assembly cross-refs
    - CLI: validate (human-friendly errors), build (--only, generator
    orchestrator with skip-not-implemented), clean
    - 23 tests incl. the 4 required negative validation cases
    rover-v1 validates except its part scripts (next stage); _test-min green.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
    [robot.yaml, test-motor.yaml]
2026-07-12 Phase 1: add generator dependencies (cad extra: cadquery/trimesh/pyrender; wireviz+numpy core)
    numba>=0.60 floor pinned: uv's universal resolution otherwise backtracks
    to numba 0.53 which cannot build on py3.11. Lock constrained to linux,
    requires-python capped <3.13.
    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
2026-07-12 Phase 1: wiring generator (WireViz harness, SVG/PNG, wire BOM)
    harness.yaml groups connections into per-instance-pair cables with
    mm lengths, non-core-side wire colors and FROM->TO wirelabels;
    wire_bom.csv is generated independently and deterministically.
    Render failures degrade to a warning; 7 tests.
    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
2026-07-12 Phase 1: bom, fw_config and catalog generators
    - firmware/config.json per frozen $5.5 (pins derived from connections,
    registry driver params verbatim; rover output asserted byte-exact)
    - bom.json/csv/md: cheapest-vendor primary + alternates, affiliate URL
    scheme SITE/out/{key}/{ref}, print-plan grams interop, totals
    - catalog.json card data (hero step image, cost, print stats, links)
    - test_cli.py stub-skip assertion repurposed now fw_config is real
    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
    [fw_config.py]
2026-07-12 Phase 1: assembly render + URDF generators
    - assembly: per-step 1600x1200 EGL renders honoring the $5.2 contract
    (ghost-grey priors, hero-color adds offset by explode, arrows along
    explode vectors, iso camera auto-framed) + deterministic steps.json
    - urdf: mm->m scaling, wheel continuous joints (axis from pose rpy),
    servo revolute path, box-approx inertials, meshes copied/synthesized
    per link; ROS-safe names (wheel@1 -> wheel_1)
    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
2026-07-12 Phase 1: print-plan and docs generators + docs sync script
    - print_plan: PrusaSlicer CLI wrapper (env/PATH discovery, pla-0.20
    profile), pure gcode-stats parser, graceful skip when slicer absent
    - docs: 10-page MDX bundle from Jinja2 templates (index/safety/source-
    parts/print-guide/wiring/assemble/flash/first-run/play/troubleshooting)
    with image copying and MDX-safe escaping of registry text
    - scripts/sync_docs.py copies dist docs into apps/docs content tree
    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
2026-07-12 Phase 1: cadlib, rover part scripts and CAD generator
    - cadlib: plate/boss_m2_selftap/pocket_sg90/clamp_n20/pocket_pcb/
    wire_channel/snapless_lip helpers, FIT=0.20, WALL_MIN=1.6; CAD_GUIDE.md
    - rover parts: chassis (motor clamps, PCB bays, USB cutout, head mount),
    wheel (D-shaft press-fit hub, grooved tire), caster (6mm ball socket),
    head (ToF window + eye holes, 10 deg face), lid (snapless lip + vents)
    - cad generator: STL/STEP/3MF export + trimesh QC (watertight, bbox,
    overhang report) + deterministic qc_report.json
    - all parts watertight, 0-1.6% overhang (support-free), 9 tests
    Claude-Session: https://claude.ai/code/session_0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
2026-07-12 Phase 1: golden-file harness, behaviors in dist, docs sync, report
    - tests/test_goldens.py: full-text goldens for _test-min, sha256 snapshot
    for rover-v1, $5.6 inventory gates, --update-goldens flag, committed
    deterministic fake slicer; CI-only real-slicer 60-180g sanity check
    - CLI build copies behaviors/*.json into dist per $5.6
    - rover + _test-min generated docs synced into apps/docs (13 pages build)
    - sharp ^0.33 for Astro image optimization
    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
    [bom.csv, robot.urdf, wire_bom.csv]
2026-07-12 Phase 1 review feedback: legible sensor/wheel assembly steps
    - assembly.yaml: stagger head/range/eyes explode vectors so each part
    reads separately; split overloaded step 10 into 'Line sensors +
    beeper' and 'Wheels + lid'; add press-fit/glue notes (wheels press
    onto motor D-shafts, no extra hardware)
    - assembly generator: gearmotor modules render with a visible output
    shaft so press-fit wheels don't look like they're missing a spindle
    - rover golden hashes + step-count test expectations updated (11 steps)
    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
2026-07-12 companion-v1: owner-approved scope addition (spec + decisions + backlog)
    Rolling AI companion with camera person-tracking, app-first chat with
    onboard-voice upgrade path. Slots into Phase 6 as robot #3; AI chat
    platform lands with Phase 7. Engine untouched per P1/P5.
    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
2026-07-12 Phase 2: /flash and /drive pages + RobotLink transport layer
    - lib/robotlink: $5.4 message types, transport-agnostic RobotLink
    interface (SimLink reuses it in Phase 3), WsLink with hello/ping
    cadence + backoff reconnect, arcade-mix + battery helpers
    - /drive: connect card (mDNS + iOS fallback copy), pointer-event
    joystick at 10Hz with zero-on-release, servo sliders from /api/config,
    LED/tone controls, telemetry bar, log console, behavior upload+run
    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
2026-07-12 Phase 2/3: Behavior VM (C++) + TS reference interpreter + shared golden traces
    - packages/behavior-ts: BSJ types, zod schema with $5.3 limits,
    BsjInterpreter with injectable RobotAdapter, SEMANTICS.md nailing
    binary32 math, tick anchoring, 200-op budget, exact error strings
    - packages/firmware/src/vm: same semantics on fixed pools (128 stmts,
    8 vars, 4x16 frames, zero heap after load), frozen Vm/VmHal API
    - 12 shared fixtures (packages/behavior-ts/fixtures) produce identical
    traces in both interpreters: 35 TS tests + 14 native VM tests green
    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
    [11_servo_sweep.json]
2026-07-12 Phase 2: universal firmware — core, drivers, provisioning, HTTP/WS API
    - core: Config ($5.5 parse + cfg_hash sha256), Log ring buffer, Net
    (STA->SoftAP fallback, captive portal, mDNS, BOOT-hold cred wipe),
    HttpApi ($5.4 endpoints + CORS), WsServer ($5.4 messages, 5Hz
    telemetry, 800ms manual-mode deadman), Ota (upload + check-on-boot)
    - drivers: 7 launch classes via string->ctor Factory; motor slew
    limiting + staggered servo attach (brownout prevention)
    - main.cpp boot sequence with VmHal bridge to driver instances
    - 6.4KB vanilla captive portal; 29 new native tests (45 total green);
    target TUs syntax-checked vs ArduinoJson 7 (xtensa build in CI)
    - $5.4 interpretation calls logged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
    [Buzzer_PWM.cpp, Factory.cpp]
2026-07-12 Phase 2: CI merged-image + flasher manifest, bench protocol, report
    - firmware-build job: buildfs + esptool merge_bin (bootloader/partitions/
    boot_app0/app/littlefs) -> firmware-merged.bin + esp-web-tools manifest
    with absolute release URLs (relative paths break behind the
    releases/latest redirect); both attached to releases on v* tags
    - docs/reports/PHASE-2.md + PHASE-2-bench.md (hardware checkpoint)
    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
2026-07-12 Phase 3: browser simulator package with SimLink and behavior gates
    - SimWorld: Rapier fixed-step 1/120s, seeded determinism (float-identical
    pose traces), URDF bbox colliders, diff-drive from URDF wheel joints,
    servo position motors, headless-safe (collidersOnly)
    - VirtualSensors: 5-ray ToF fan (25deg FOV, sigma 2mm), ground-field line
    sensors 0-4095, battery discharge model
    - Arenas: open_floor, line_oval (parametrized track), obstacle_pen (seeded)
    - SimLink implements the $5.4 RobotLink protocol; BsjInterpreter at 50Hz
    - Gates green: avoid_obstacles 1.614m/15s no wall-hugging; line_follow
    197.9% lap progress; 35 tests
    Claude-S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
    [buzz.stl, caster_mount.stl, chassis.stl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]
2026-07-12 Phase 3: /play — sim canvas + block editor, one program both worlds
    - split view: three.js render of SimWorld (orbit camera, arena picker,
    1x/4x speed, BOOT button, LED/status overlay) + reused BlockEditor
    - session wiring (pure, tested): Run in Sim (zod -> loadBehavior -> run),
    Stop, Reset, Send to Robot (POST /api/behavior + ctl run, then live
    WsLink logs/telemetry); merged sim/robot console
    - BlockEditor extracted from /builder (identical behavior, shared
    localStorage); rover URDF+meshes served from /sim-assets
    - 21 new tests (web at 107); heavy chunks all lazy (89.4kB first load)
    Claude-Session: https://claude.ai/code/sess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
    [buzz.stl, caster_mount.stl, chassis.stl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]
